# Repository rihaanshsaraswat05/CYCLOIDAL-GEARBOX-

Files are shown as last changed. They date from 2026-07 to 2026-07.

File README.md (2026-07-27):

<!-- ================================================================ -->
<!--  README.md  —  Mechanical Design Repository                      -->
<!--  Replace all [PLACEHOLDER] text and image paths before pushing.  -->
<!-- ================================================================ -->

<h1 align="center"> 3D PRINTED CYCLOIDAL GEARBOX </h1>
<p align="center">
  <em>["30:1 Cycloidal Gearbox for steering , actuation joints of arm link1 & 2 Mars Rover"]</em>
</p>

<p align="center">
  
  
  
</p>

---

## 📖 Overview

This repository contains the complete mechanical design package for **[CGB]**, developed by **[RIHAANSH SARASWAT MECH LEAD]**. It includes native CAD source files, manufacturing-ready drawings, 3D-printable/exportable mesh files, and full assembly documentation.

**THIS GEAR BOX IS A PROTOTYPE VERSION OF THE MARKET LEVEL CYCLOIDAL GEARBOX WITH 3D PRINTED CARBON FIBER INDUCED FILAMENT IT PROVIDES AN IDEAL 30:1 GEAR REDUCTION USING 2 PHASE CYCLOIDAL DISCS IWTH 31 RING PINS AND 6 DOWEL PINS THIS VERSION USES A NON BACKDRIVABLE WORM GEARED MOTOR AND A FLEXIBLE JAY COUPLING IN ORDER TO TEST AND MALFUCTION FOR ANY USE** 

### 📁 Repository Structure

| Folder | Contents | Format(s) |
|---|---|---|
| `CAD/` | Native, editable part & assembly files | `.SLDPRT`, `.SLDASM`, `.step` |
| `Drawings/` | Manufacturing / engineering drawings with GD&T, dimensions, tolerances | `.pdf`, `.SLDDRW` |
| `STL/` | Exported meshes for 3D printing, simulation, or viewing | `.stl` |
| `Renders/` | Rendered images used for documentation/marketing | `.png`, `.jpg` |
| `BOM/` | Bill of materials, part sourcing sheets | `.xlsx`, `.csv` |
| `docs/` | Supporting documentation, images used in this README | — |

> 💡 Tip: Start with `CAD/` if you plan to modify the design, `Drawings/` if you're sending parts out for manufacturing, and `STL/` if you just need to print or view geometry quickly.

---

## 🖼️ Design Preview

<table>
  <tr>
    <td width="50%">
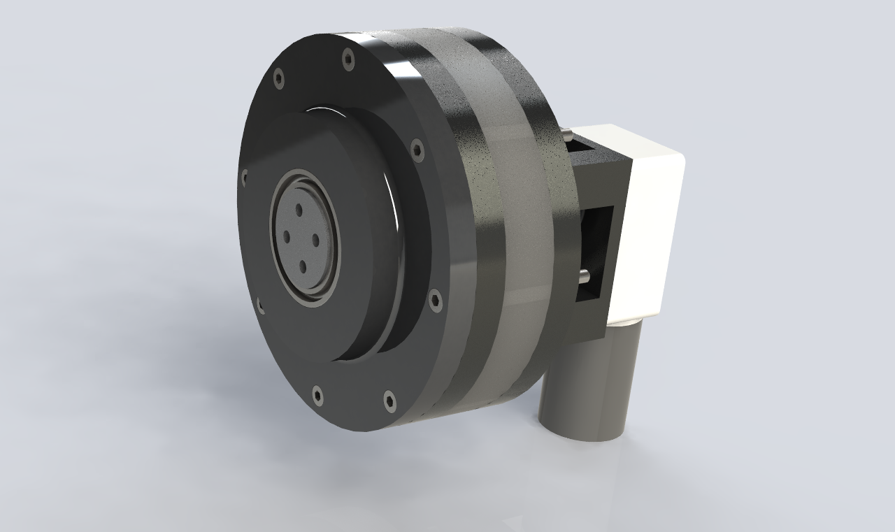
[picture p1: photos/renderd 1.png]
Front rendered view
      
      <p align="center"><b>Front Isometric Render</b><br>[Short description — e.g. "Assembled gearbox showing the twin-disc cycloidal stage and output flange."]</p>
    </td>
    <td width="50%">
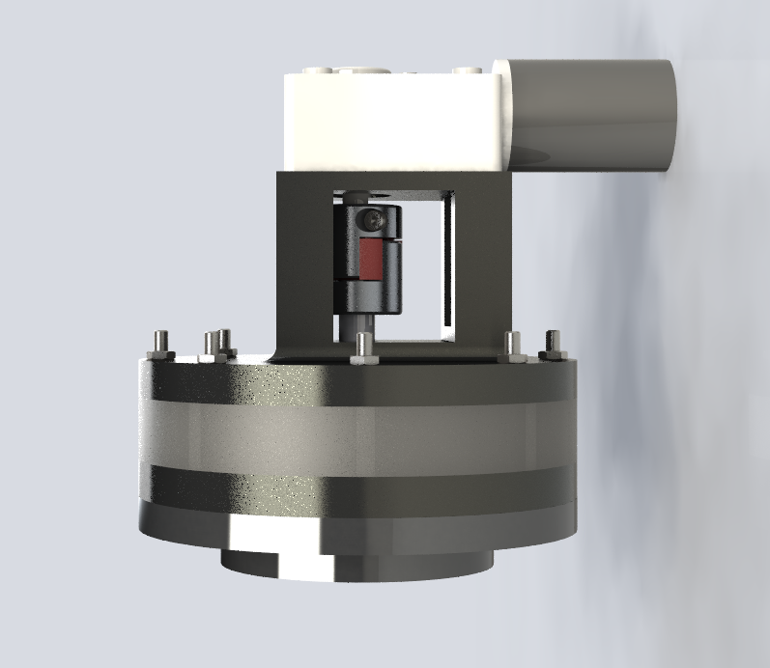
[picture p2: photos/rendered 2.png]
Exploded rendered view
      
      <p align="center"><b>Exploded View Render</b><br>[Short description — e.g. "Exploded assembly highlighting bearing placement, ring pins, and disc stack order."]</p>
    </td>
  </tr>
  <tr>
    <td colspan="2">
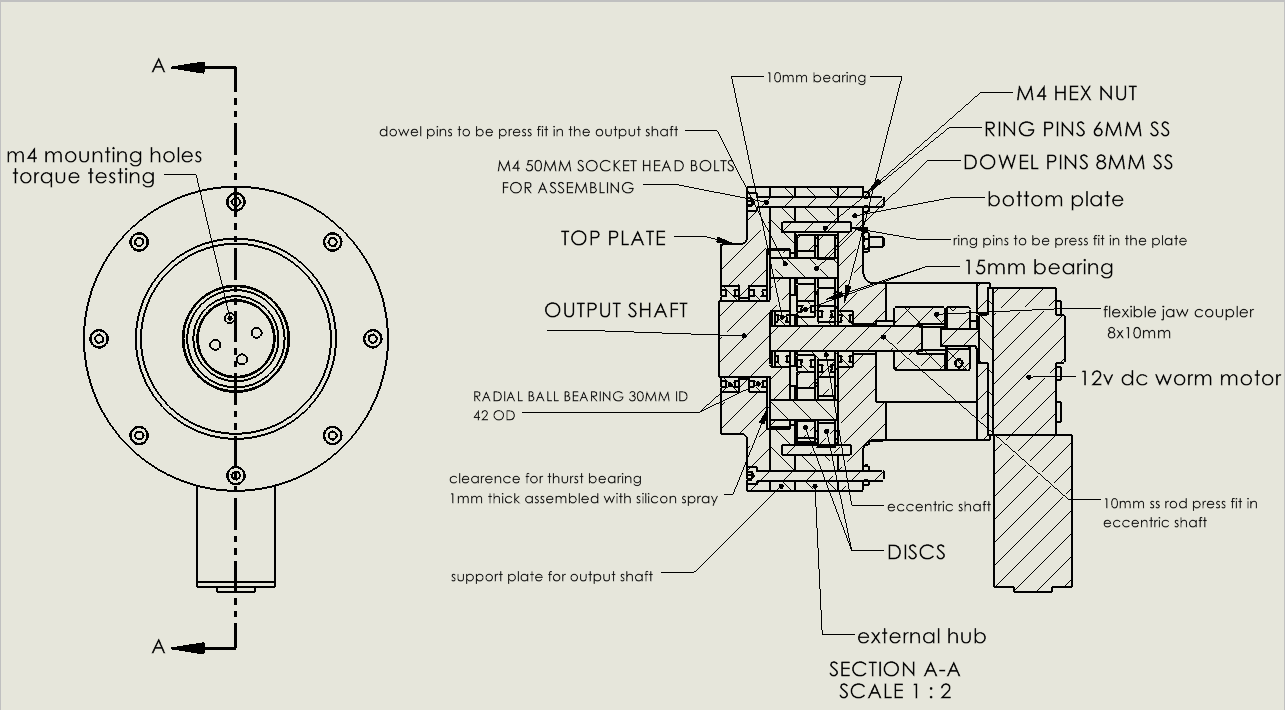
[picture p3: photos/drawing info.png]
2D engineering drawing
      
      <p align="center"><b>2D Engineering Drawing</b><br>[Short description — e.g. "Full manufacturing drawing of the Cycloidal gearbox with critical dimensions, tolerances, and section views."]</p>
    </td>
  </tr>
</table>

---

## Manufacturing Details

| Part | Manufacturing Process | Material | Specifications | Notes |
|---|---|---|---|---|
| **Bottom Plate** | FDM 3D Printing | PLA | 0.20 mm layer height, 70–80% infill | Print with the mounting face on the build plate. Ensure bearing bores are dimensionally accurate. Avoid support material inside bearing seats. |
| **Top Plate** | FDM 3D Printing | PLA | 0.20 mm layer height, 70–80% infill | Print with the bearing seat facing upward for better dimensional accuracy. |
| **Cycloidal Disc** | FDM 3D Printing | PLA-CF / PPA-CF | 0.16–0.20 mm layer height, 80–100% infill | Print flat on the build plate. High-strength material is required due to continuous pin contact and wear. |
| **Output Shaft** | FDM 3D Printing | PPA-CF / PLA-CF | 0.16–0.20 mm layer height, 60–80% infill | Print vertically with 4–6 walls to maximize strength around the bearing seats. |
| **Eccentric Shaft** | FDM 3D Printing | PPA-CF / PLA-CF | 0.16–0.20 mm layer height, 60–80% infill | Print vertically with thick walls for maximum concentricity and strength. |
| **External Hub** | FDM 3D Printing | PLA | 0.20 mm layer height, 40–60% infill | Medium infill is sufficient. Ensure proper fit with the ring pins. |
| **Ring Pins** | CNC Turning / Precision Ground Rod | SS304 Stainless Steel | Ø6 mm Ground Rod | Maintain tight diameter tolerance and smooth surface finish for low friction. |
| **External Shaft** | CNC Turning | SS304 Stainless Steel | As per drawing | Maintain interference fit dimensions with the 10 mm shaft. |
| **10 mm Shaft** | CNC Turning | SS304 Stainless Steel | Ø10 mm | Ensure accurate bearing and coupler fit with smooth surface finish. |
| **Bearings** | Standard Purchased Component | Chrome Steel | 6902 Series | Use sealed/shielded bearings. Avoid applying assembly force through the rolling elements. |
| **Fasteners** | Standard Purchased Component | Stainless Steel | A2-70 | Use the specified tightening torque during final assembly. |
| **Coupler** | Standard Purchased Component | Aluminum | Flexible Shaft Coupler | Select bore sizes according to the motor shaft and 10 mm shaft dimensions. |
| **Thrust Washer** | Standard Purchased Component | Hardened Steel | Ø10 mm ID | Lubricate lightly with silicone spray during assembly. |

> **Manufacturing Notes**
>
> - Deburr all machined components before assembly.
> - Verify all press-fit dimensions before installing bearings and shafts.
> - Clean all bearing seats and shaft surfaces before assembly.
> - Apply silicone spray only to the shaft and thrust washer interface; avoid contaminating bearing races.
> - Check dimensional tolerances of all 3D-printed parts before assembly, especially bearing bores, shaft holes, and ring pin holes.
> - Ream printed holes if necessary to achieve the specified interference or clearance fit.
> - Inspect printed parts for warping or layer separation before use.

**General notes:**
- All drawings in `Drawings/` include full GD&T callouts — always manufacture from these, not raw CAD geometry.
- STL files in `STL/` are for visualization/printing only and are **not dimensionally toleranced** for CNC/EDM work.

---

## 🔧 Assembly Information

1. **Mount the shaft coupler** onto the motor shaft, ensuring proper alignment and securely tightening the set screws as per the specified torque.

2. **Press-fit the bearings** into the bottom plate using an arbor or hydraulic press, ensuring force is applied only to the bearing's outer race.

3. **Press-fit the ring pins** into the bottom plate and simultaneously install the external hub, ensuring all pins are fully seated and positioned according to the assembly drawing.

4. **Press-fit the external shaft** onto the 10 mm shaft, ensuring proper alignment and a secure interference fit.

5. **Press-fit the 15 mm bearing** onto the eccentric shaft by applying force only to the bearing's inner race.

6. **Insert the 10 mm shaft** into the bottom plate while installing the 10 mm thrust washer. Apply a light coating of silicone spray to the mating surfaces to facilitate assembly and reduce friction.

7. **Mount the motor** onto the bottom plate and connect it to the shaft using the pre-installed coupler. Secure the motor with the specified fasteners.

8. **Install the cycloidal discs** onto the eccentric shaft, ensuring the discs are correctly oriented and phased according to the design.

9. **Press-fit the bearings** into the output shaft and install all 8 mm dowel pins in their designated locations.

10. **Assemble the output shaft** with the cycloidal discs and install the output shaft support, ensuring smooth engagement of all output pins.

11. **Press-fit the bearings** into the top plate, applying force only to the bearing's outer race.

12. **Assemble the top plate** onto the output shaft assembly, align all mounting holes, and secure the complete gearbox using the long M4 bolts. Tighten the bolts uniformly in a crisscross sequence using a drill machine, followed by final torque tightening as specified.

Refer to the exploded render above and the assembly drawing in `Drawings/` for exact part orientation and fastener callouts.

---

## ⚠️ Cautions — Manufacturing & Assembly

- **Tolerances:** Cycloidal disc lobe profiles are tolerance-critical — verify machined parts against the drawing before assembly; even small deviations can cause binding.
- **Bearing press-fits:** Never press bearings using the inner race when installing onto a shaft, or the outer race when installing into a housing — this can damage the balls/races.
- **Handling ground/hardened parts:** Handle hardened discs and ground pins carefully to avoid surface nicks, which can cause premature wear or noise.
- **Cleanliness:** Ensure all parts are cleaned and deburred before assembly — trapped swarf/debris is a common cause of gearbox failure.
- **Fastener torque:** Follow specified torque values; over-torquing housing fasteners can warp thin-walled sections.
- **Phase alignment:** For twin-disc cycloidal designs, confirm the 180° phase offset is correct before final fastening — incorrect phasing causes vibration and uneven load sharing.
- **Orientation:** Double-check asymmetric parts (e.g. eccentric shafts, off-center flanges) against the drawing — incorrect orientation is not always visually obvious.

---

## 📄 License
This project is licensed under the MIT License. See the `LICENSE` file for details.

## 🙌 Credits

Developed by **RIHAANSH SARASWAT**, TEAM DEIMOS , IIT MANDI.

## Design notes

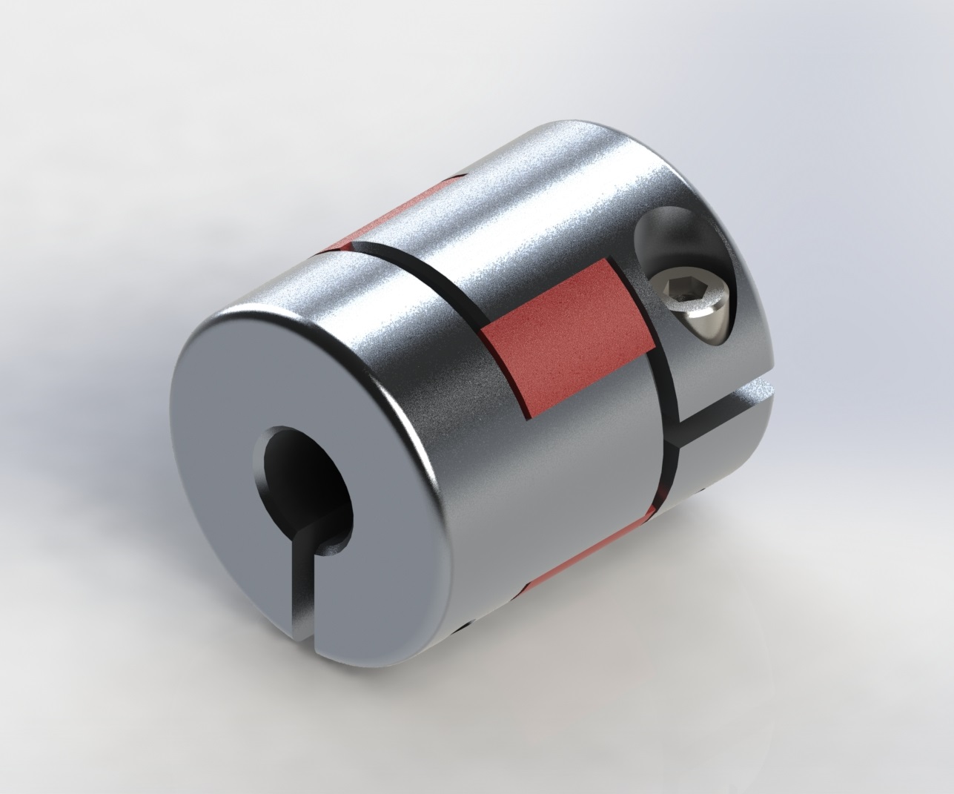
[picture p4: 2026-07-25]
CAD/jaw-coupling-8x10mm-1.snapshot.1/Jaw 8x10 - iso.JPG

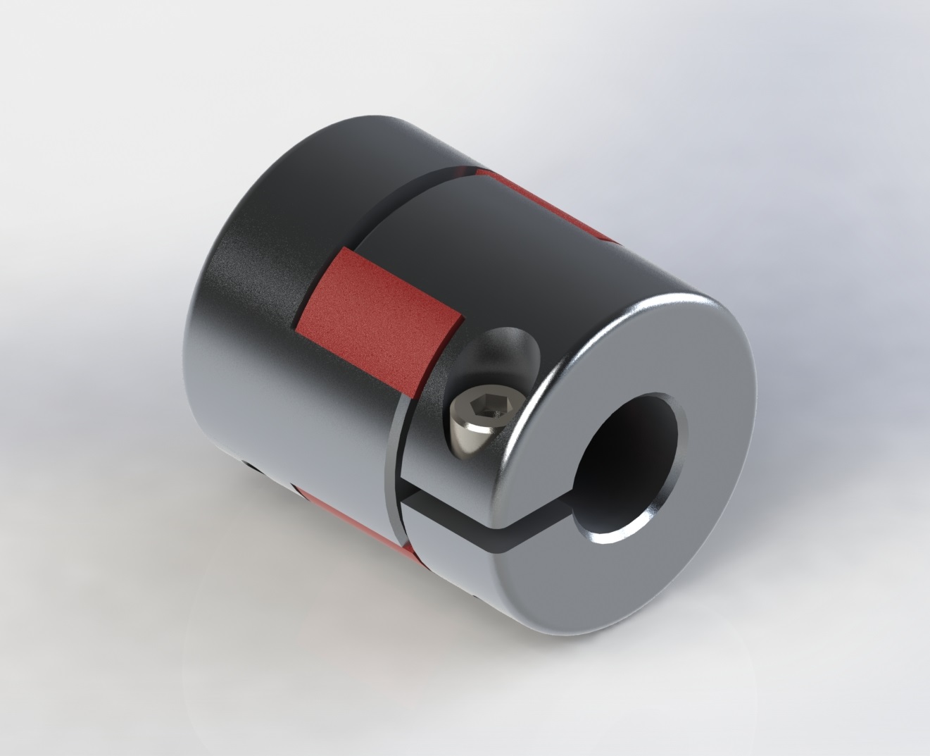
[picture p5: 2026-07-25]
CAD/jaw-coupling-8x10mm-1.snapshot.1/Jaw 8x10 - iso-r.JPG

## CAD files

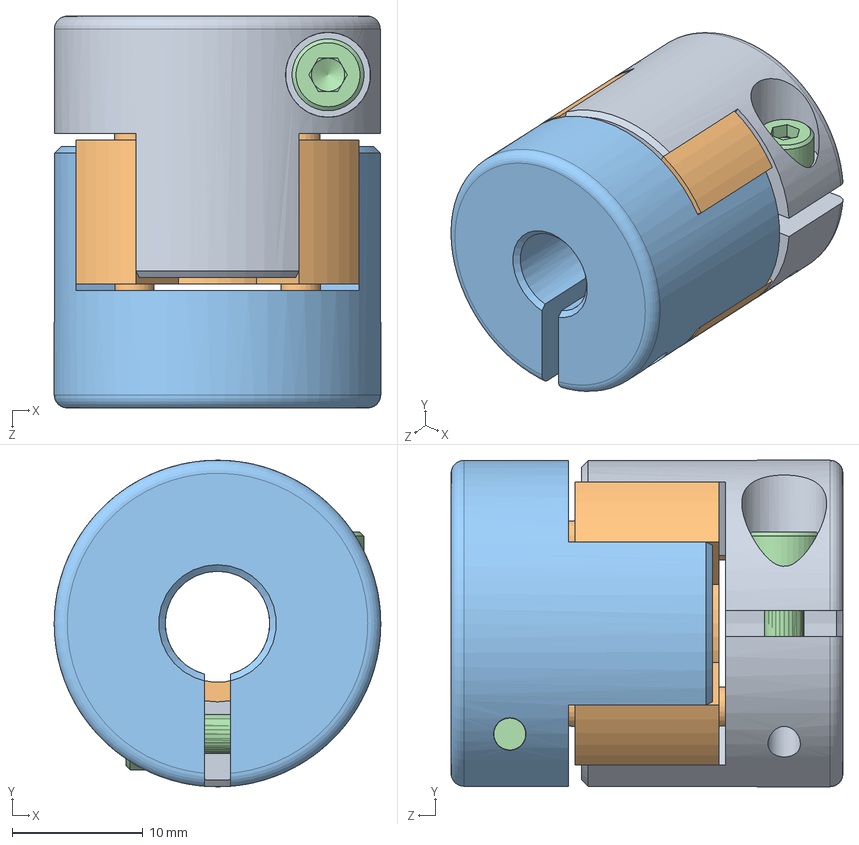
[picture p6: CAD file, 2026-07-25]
CAD/jaw-coupling-8x10mm-1.snapshot.1/Acoplamento Jaw 8x10 D=25 L=30/Acoplamento Jaw 8x10 d=25 L=30.SLDASM
25.0 x 25.0 x 30.0 mm
Lateral Al furo=10
Aranha D=25mm
Lateral Al furo=8
socket head cap screw_am x 2

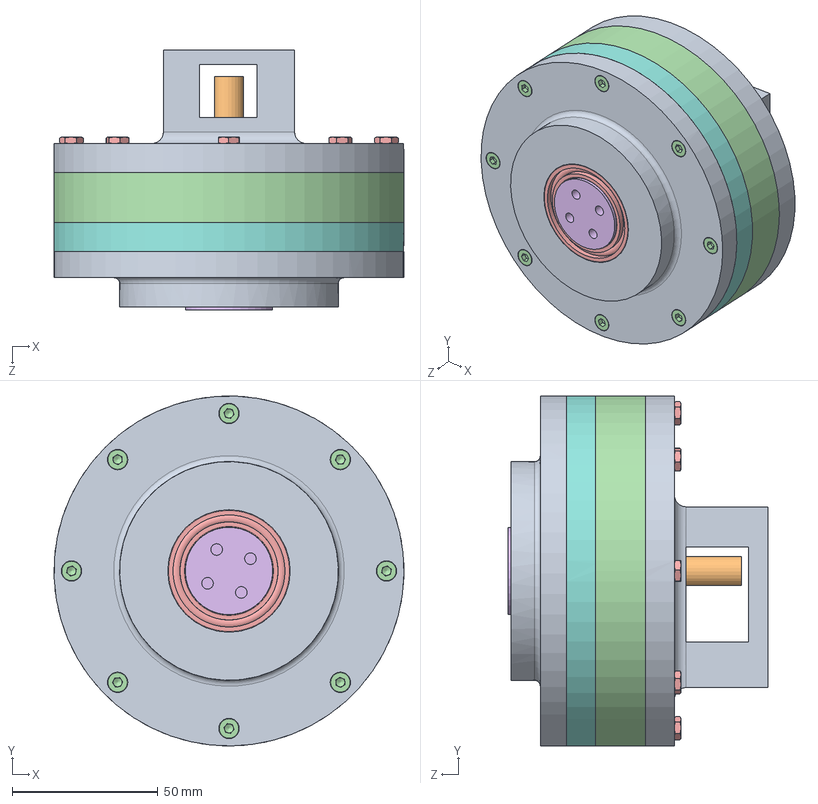
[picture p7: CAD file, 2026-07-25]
CAD/DISC_TOLERENCE CHECK/mofified cgb _shrinkage distance - 2mm.SLDASM
120.0 x 120.0 x 89.0 mm
dowel pins x 31
eccentric shaft
radial ball bearing_68_iso x 4
inside pins x 6
10mm ss rod
10mm thrust washer
socket head cap screw_iso x 8
hex thin nut chamfered gradeab_iso x 8
disc shrinked - 2mm

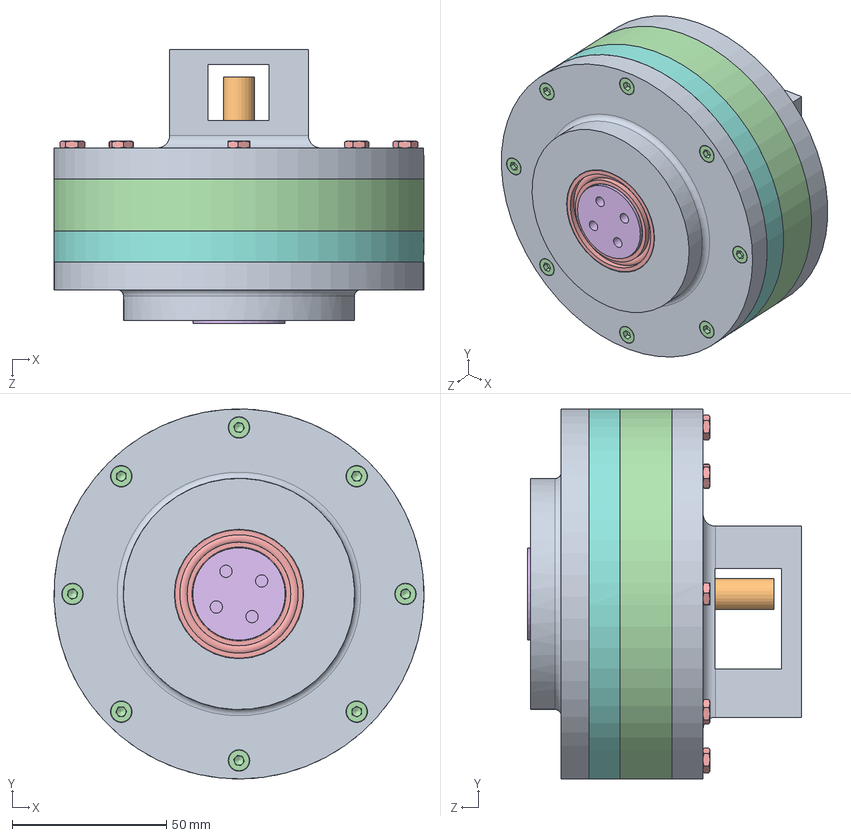
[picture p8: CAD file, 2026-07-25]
CAD/DISC_TOLERENCE CHECK/mofified cgb _shrinkage distance - 1mm.SLDASM
120.0 x 120.0 x 89.0 mm
dowel pins x 31
eccentric shaft
radial ball bearing_68_iso x 4
inside pins x 6
10mm ss rod
10mm thrust washer
socket head cap screw_iso x 8
hex thin nut chamfered gradeab_iso x 8
shrinked disc

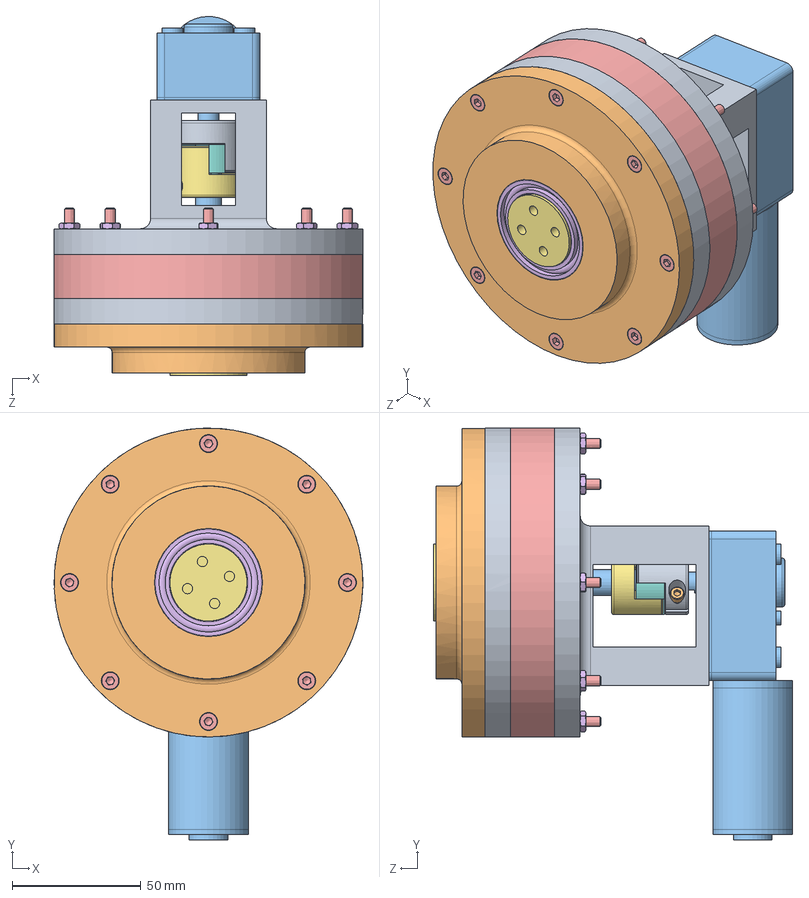
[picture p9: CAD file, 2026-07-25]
CAD/my cgb.SLDASM
120.0 x 160.0 x 139.5 mm
bottom plate
disc x 2
dowel pins x 31
eccentric shaft
outer hub
radial ball bearing_68_iso x 6
output shaft
inside pins x 6
top plate _ 1
TOP PLATE
10mm ss rod
10mm thrust washer
long bolt m4 60 x 8
hex thin nut chamfered gradeab_iso x 8
Lateral Al furo=10
Aranha D=25mm
Lateral Al furo=8
socket head cap screw_am x 2
Worm_Gear_Motor_12V.stp

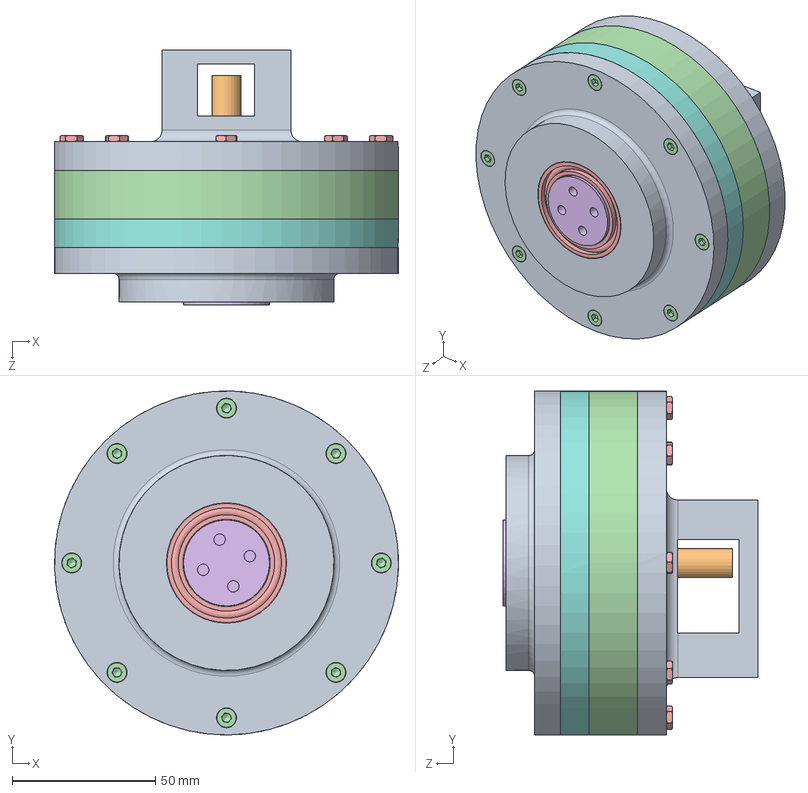
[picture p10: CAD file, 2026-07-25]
CAD/mofified cgb _shrinkage distance - 3mm.SLDASM
120.0 x 120.0 x 89.0 mm
bottom plate
dowel pins x 31
eccentric shaft
outer hub
radial ball bearing_68_iso x 6
output shaft
inside pins x 6
top plate _ 1
TOP PLATE
10mm ss rod
10mm thrust washer
socket head cap screw_iso x 8
hex thin nut chamfered gradeab_iso x 8
shrinked disc x 2

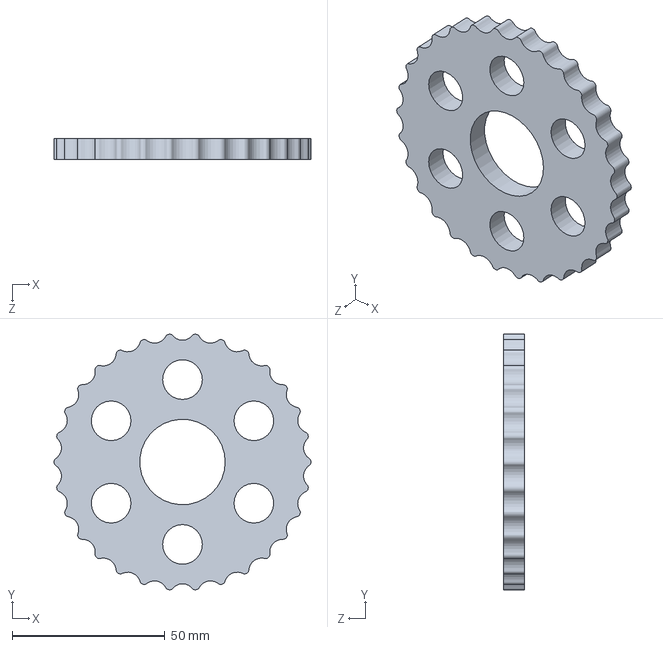
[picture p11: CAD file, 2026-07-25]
CAD/disc.SLDPRT
84.2 x 83.7 x 7.00 mm

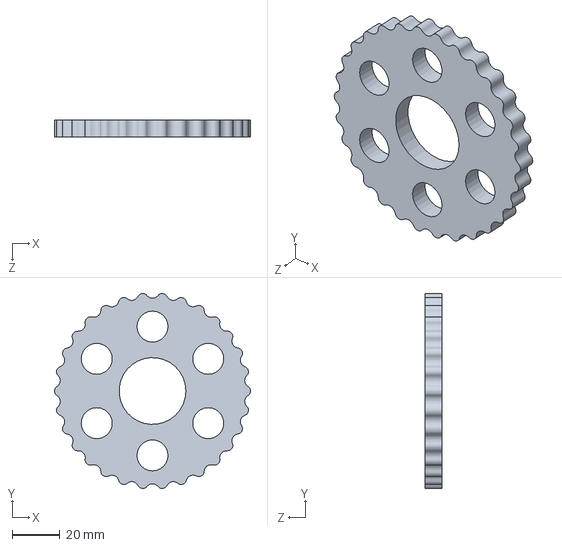
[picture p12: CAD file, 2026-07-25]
CAD/DISC_TOLERENCE CHECK/disc shrinked - 2mm.SLDPRT
82.2 x 81.8 x 7.00 mm

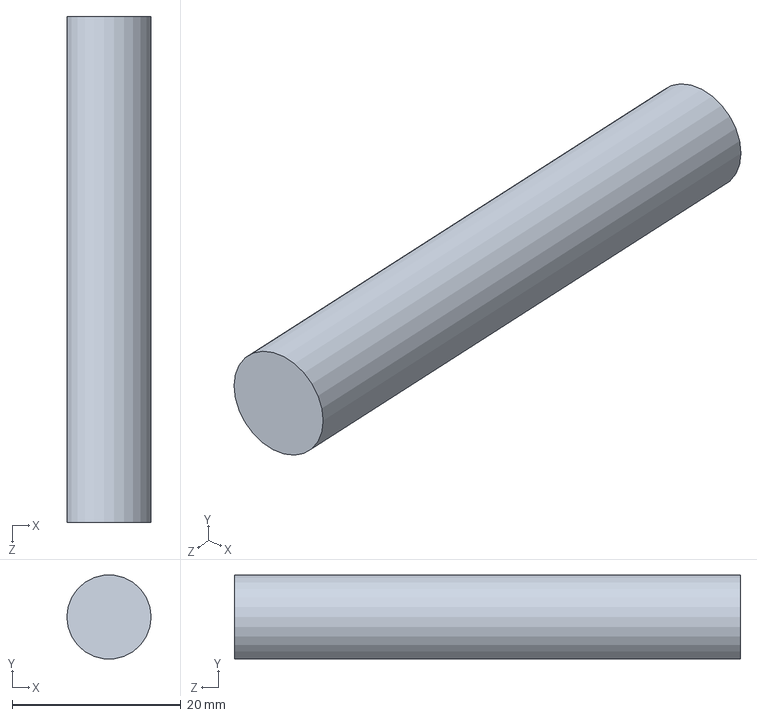
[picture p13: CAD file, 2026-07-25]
CAD/10mm ss rod.SLDPRT
10.0 x 9.93 x 60.0 mm

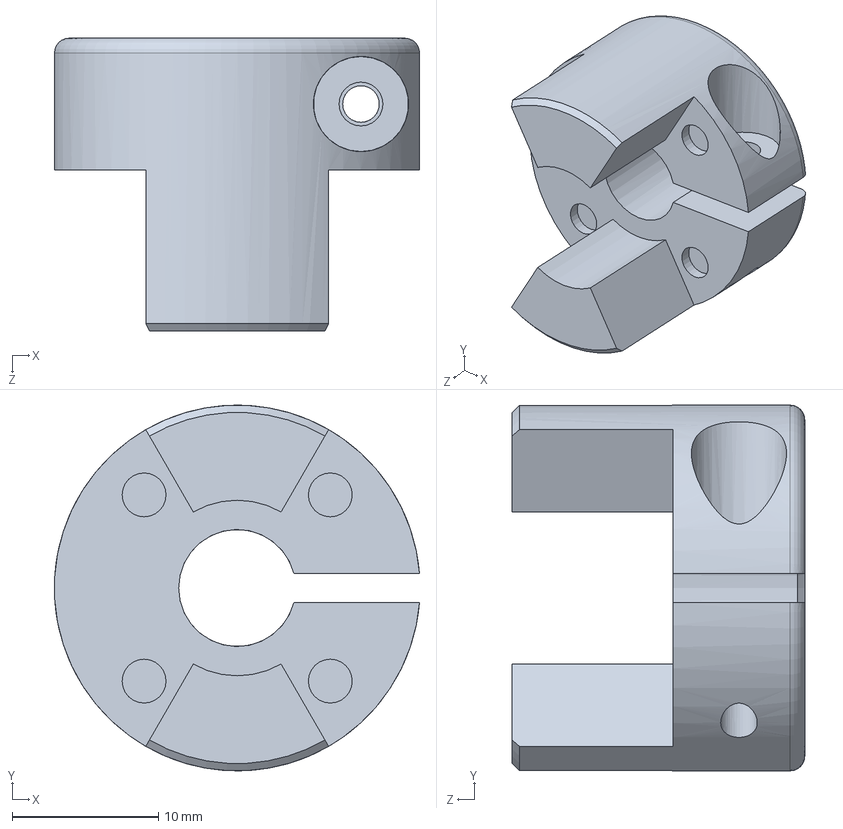
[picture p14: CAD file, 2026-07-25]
CAD/jaw-coupling-8x10mm-1.snapshot.1/Acoplamento Jaw 8x10 D=25 L=30/Lateral Al furo=8.SLDPRT
24.9 x 25.0 x 20.0 mm

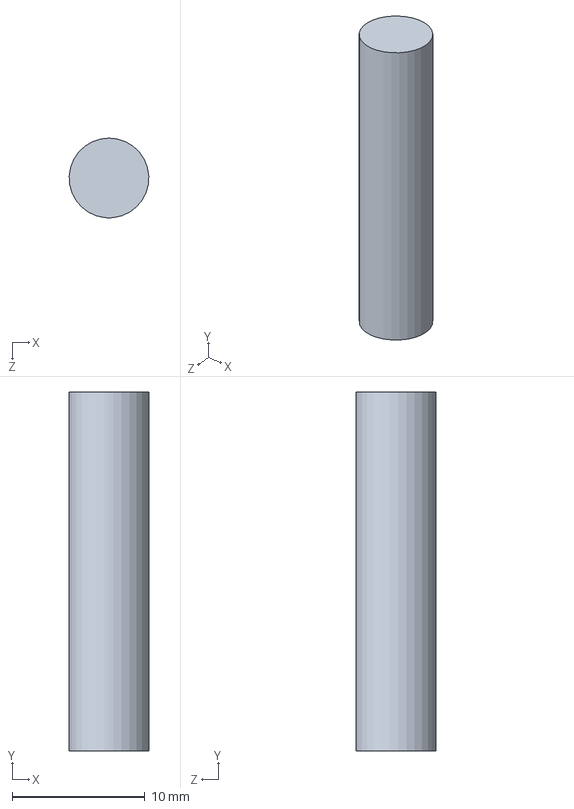
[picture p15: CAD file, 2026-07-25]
CAD/dowel pins.SLDPRT
5.99 x 27.0 x 6.00 mm

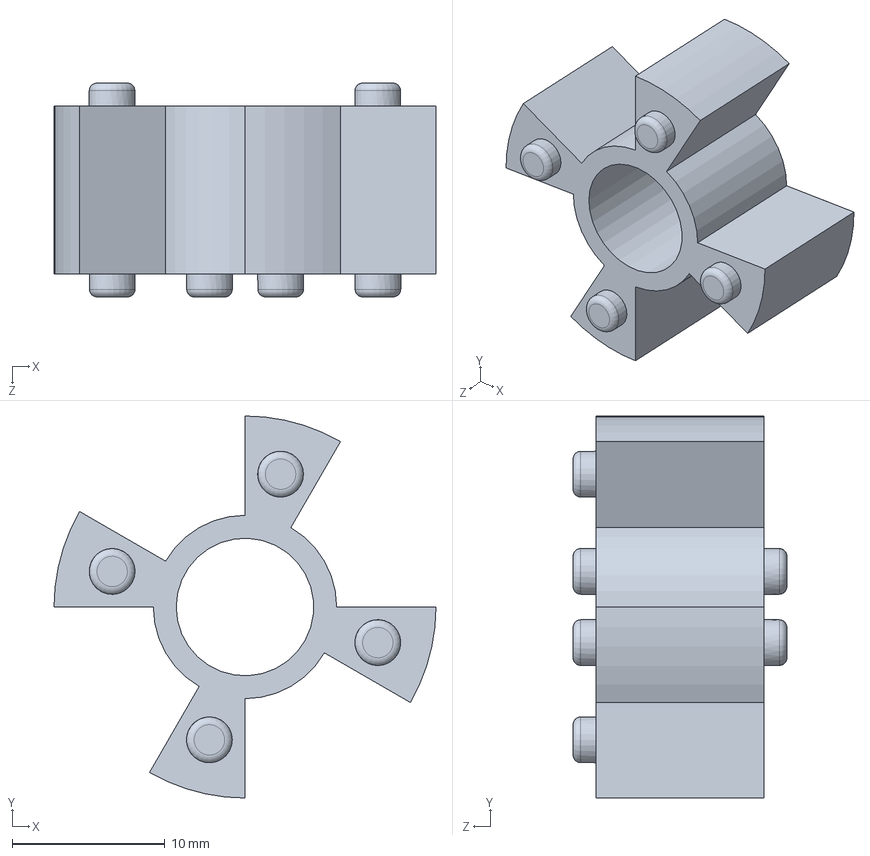
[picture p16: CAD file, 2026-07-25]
CAD/jaw-coupling-8x10mm-1.snapshot.1/Acoplamento Jaw 8x10 D=25 L=30/Aranha D=25mm.SLDPRT
25.0 x 25.0 x 14.0 mm

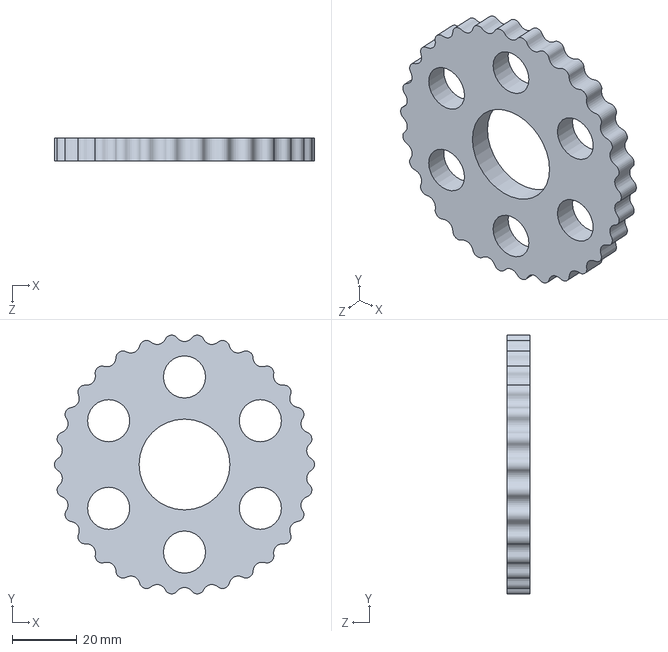
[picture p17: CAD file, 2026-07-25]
CAD/DISC_TOLERENCE CHECK/shrinked disc.SLDPRT
80.2 x 79.8 x 7.00 mm

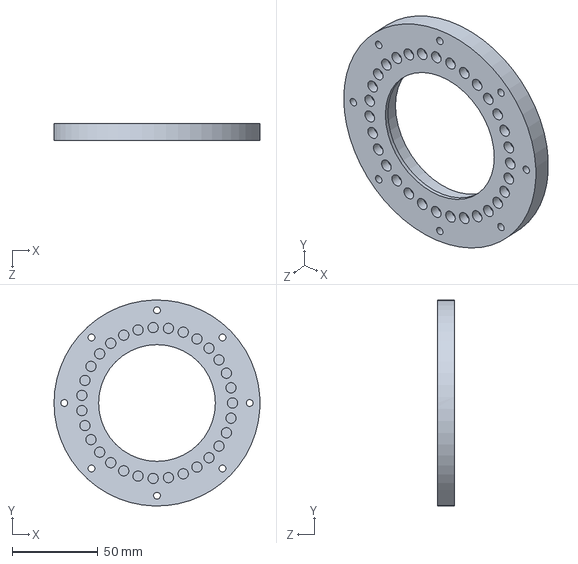
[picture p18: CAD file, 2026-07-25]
CAD/top plate _ 1.SLDPRT
120.0 x 119.9 x 10.0 mm

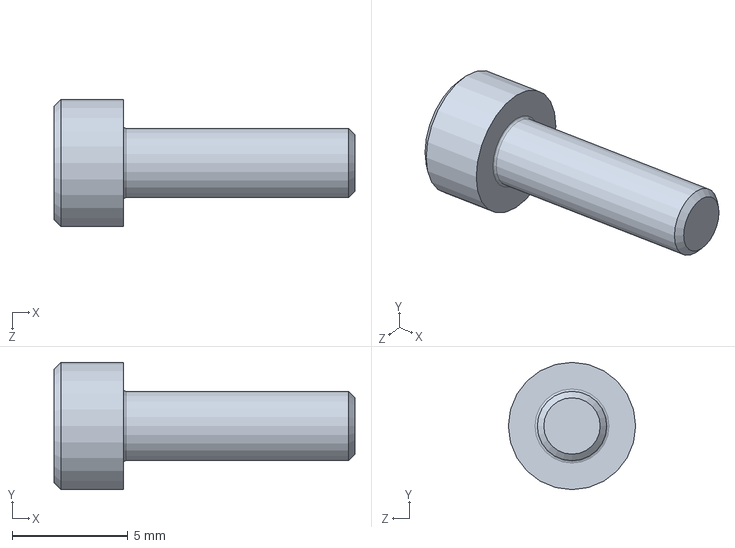
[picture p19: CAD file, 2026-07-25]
CAD/jaw-coupling-8x10mm-1.snapshot.1/Acoplamento Jaw 8x10 D=25 L=30/Parafuso allen M3x10.SLDPRT
13.0 x 5.50 x 5.50 mm

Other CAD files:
CAD/DISC_TOLERENCE CHECK/shrinkage - 1mm disc.SLDPRT
CAD/jaw-coupling-8x10mm-1.snapshot.1/Acoplamento Jaw 8x10 D=25 L=30/Lateral Al furo=10.SLDPRT
CAD/output shaft.SLDPRT
CAD/outer hub.SLDPRT
CAD/10mm thrust washer.SLDPRT
CAD/TOP PLATE.SLDPRT
CAD/bottom plate.SLDPRT
CAD/eccentric shaft.SLDPRT
CAD/inside pins.SLDPRT
CAD/jaw-coupling-8x10mm-1.snapshot.1/Acoplamento Jaw 8x10 D=25 L=30/Acoplamento Jaw 8x10 d=25 L=30.SLDPRT
STL/eccentric shaft.STL
STL/outer hub.STL
drawings/my cgb.SLDDRW

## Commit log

2026-07-25 Create my cgb.SLDDRW
    [my cgb.SLDDRW]
2026-07-25 Create README.md for mechanical design repository
    Added a comprehensive README for the mechanical design repository, including sections on overview, repository structure, design preview, material information, manufacturing details, assembly informat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
2026-07-25 Update title and use case description in README

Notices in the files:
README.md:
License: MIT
